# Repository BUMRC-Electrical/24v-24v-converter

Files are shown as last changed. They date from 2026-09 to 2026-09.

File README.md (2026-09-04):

<!-- kicad_template/README.md -->

<div align="center">
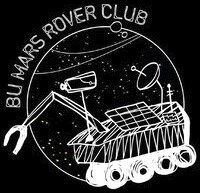
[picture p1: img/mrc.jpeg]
    
</div>

## 24V-24V 35 Amp Converter

This repository contains all documentation and files for the custom 24V Converter.

## File Structure

- ```/kicad/``` contains all of the KiCad 10.0 project files
- ```/datasheets/``` contains all of the .pdf files for the important components
- ```/calculations/``` contains significant calculations that led to a component choice or value choice
- ```/cad/``` currently contains no files
- ```24V_BOM.xlsx``` contains all components, quantities, and links to purchase

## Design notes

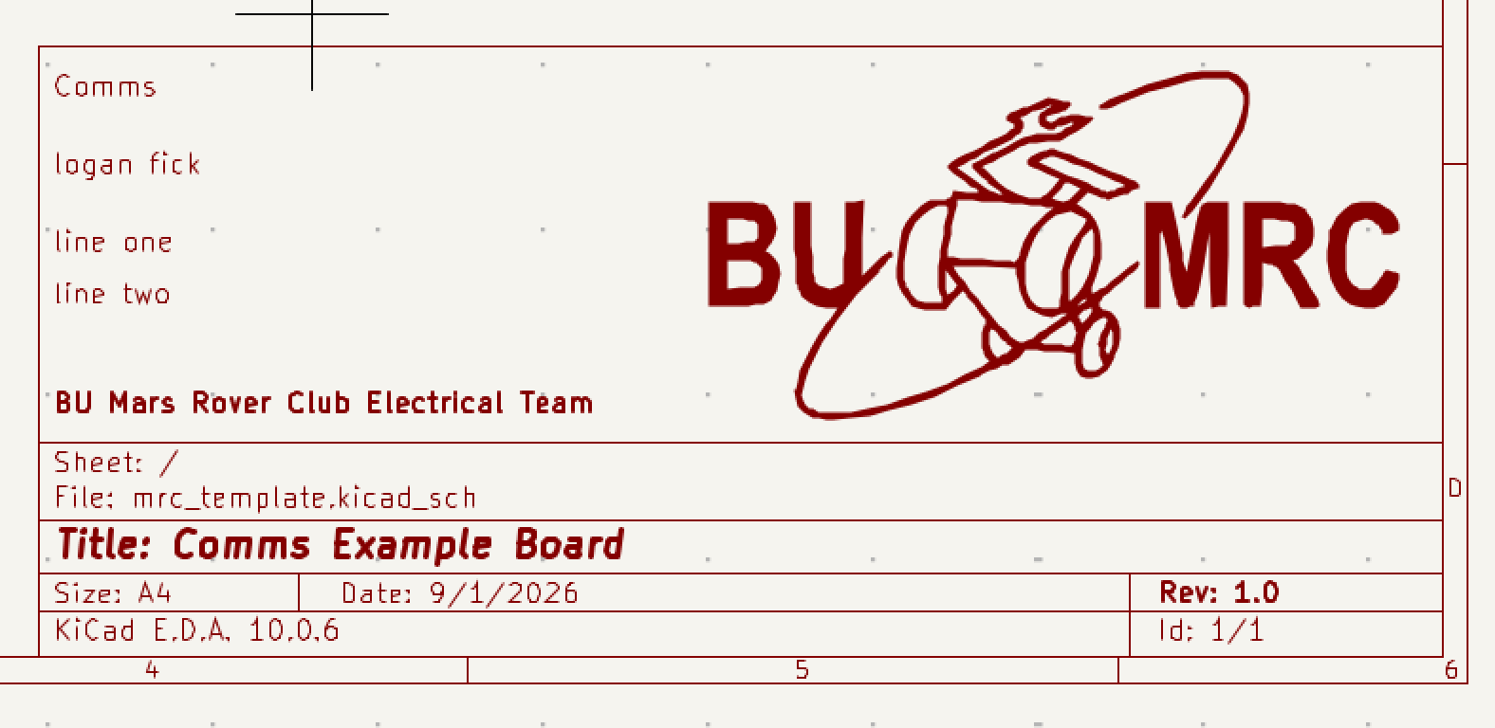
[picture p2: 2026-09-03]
img/fields.png

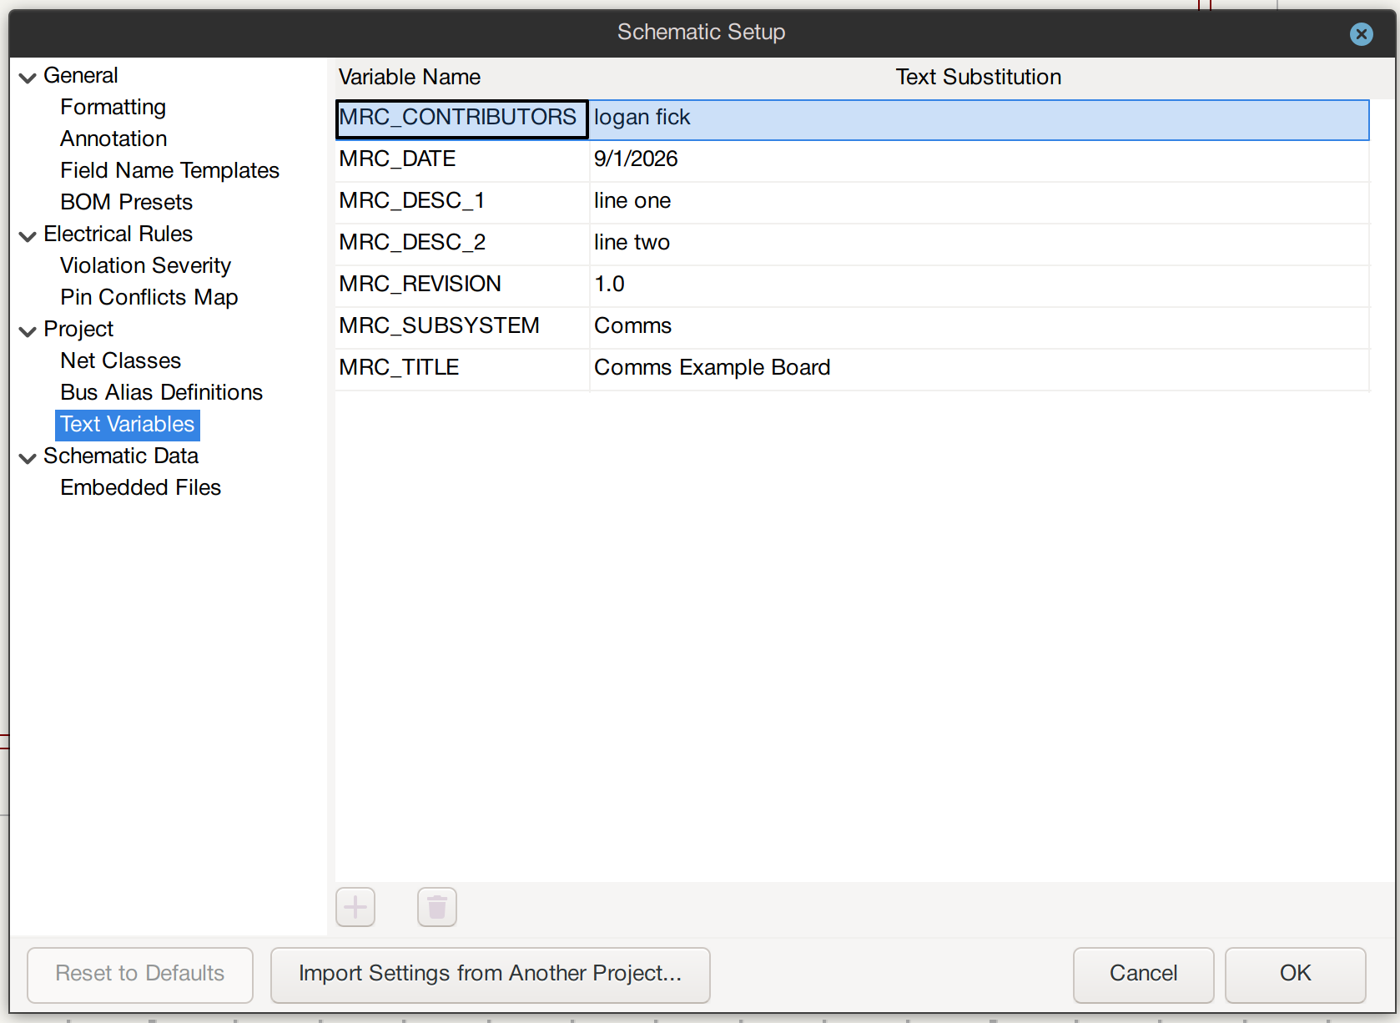
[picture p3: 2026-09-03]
img/text_variables.png

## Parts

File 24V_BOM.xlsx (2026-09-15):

Part | Part Number | Quantity | Footprint (mm²) | Description | Link | Replacement
Rvisns | CRCW04022K00FKED | 1 | 3 | Resistance: 2 kΩ Tolerance: 1.0% Power: 63 mW | https://www.digikey.com/en/products/detail/vishay-dale/CRCW04022K00FKED/1178039 | https://www.digikey.com/en/products/detail/stackpole-electronics-inc/RNCF0603TKY2K00/4928382
M1 & M2 | CSD18540Q5B | 4 | 56 | VdsMax: 60 V IdsMax: 200 Amps | https://www.mouser.com/en/ProductDetail/Texas-Instruments/CSD18540Q5B?qs=NRIcxvoDUteMaKTIEMaARQ%3D%3D
Cboot1/Cboot2 | 06033C104KAT2A | 2 | 4.68 | Cap: 100 nF Total Derated Cap: 100 nF VDC: 25 V ESR: 50 mΩ Package: 0603 | https://www.digikey.com/en/products/detail/kyocera-avx/KGM15BR71E104KT/1116240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
Rf | RC0603FR-0710RL | 1 | 4.68 | Resistance: 10 Ω Tolerance: 1.0% Power: 100 mW | https://www.digikey.com/en/products/detail/yageo/RC0603FR-0710RL/726879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 | https://www.digikey.com/en/products/detail/stackpole-electronics-inc/RNCF0805TKY10K0/2269701
Rcomp | CRCW04022K10FKED | 1 | 3 | Resistance: 2.1 kΩ Tolerance: 1.0% Power: 63 mW | https://www.digikey.com/en/products/detail/vishay-dale/CRCW04022K10FKED/1178041 | https://www.digikey.com/en/products/detail/koa-speer-electronics-inc/RK73H2ATTD1002F/10234111
Rpg | RC0603FR-0710KL | 1 | 4.68 | Resistance: 10 kΩ Tolerance: 1.0% Power: 100 mW | https://www.digikey.com/en/products/detail/yageo/RC0603FR-0710KL/726880
C32, C33 | MSASH21GSB7153MTNA01 | 2 | 6.75 | Cap: 15 nF Total Derated Cap: 30 nF VDC: 100 V ESR: 1.25 Ω Package: 0805 | https://www.digikey.com/en/products/detail/kyocera-avx/08051C163JAT2A/1601344
C34 | GRM2195C1H152JA01D | 1 | 6.75 | Cap: 1.5 nF Total Derated Cap: 1.5 nF VDC: 50 V ESR: 0 Ω Package: 0805 | https://www.digikey.com/en/products/detail/murata-electronics/GRM2195C1H152JA01D/2545206
Dboot1 & Df | CUSTOM | 2 | NA | Type: ? VRRM: 36 V Io: 200 mA | https://www.digikey.com/en/products/detail/onsemi/BAS16HT1G/918301
Rsense | FCSL64R002GER | 1 | 43.16 | Resistance: 2 mΩ Tolerance: 2.0% Power: 2 W | https://www.digikey.com/en/products/detail/ohmite/FCSL64R002GER/1853755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
Dboot2 | CDBK0540-HF | 1 | 11.7 | Type: Schottky VRRM: 40 V Io: 500 mA | https://www.digikey.com/en/products/detail/mcc-micro-commercial-components/MBR0540-TP/717252
U1 | LM5176PWPR | 1 | 98.28 |  | https://www.digikey.com/en/products/detail/texas-instruments/LM5176PWPR/8105935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
C1-C7 | 50SVPF10M | 7 | 73.96 | Cap: 10 µF Total Derated Cap: 70 µF VDC: 50 V ESR: 40 mΩ Package: 6.3x6 | https://www.digikey.com/en/products/detail/panasonic-industry/50SVPF10M/4209237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 | https://www.digikey.com/en/products/detail/panasonic-industry/50SVPK10M/7564810
Cvcc | EMK107B7105KA-T | 1 | 4.68 | Cap: 1 µF Total Derated Cap: 1 µF VDC: 16 V ESR: 1 mΩ Package: 0603 | https://www.digikey.com/en/products/detail/taiyo-yuden/EMK107B7105KA-T/930593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
L1 | CUSTOM | 1 | NA | L: 1.25 µH DCR: 3.43 mΩ IDC: 56.94 A Data Sheet Recomends: 12.7µH and 16.5 A | https://www.digikey.com/en/products/detail/bourns-inc/SRP1770TA-100M/5429634
Ccs | 06035A470JAT2A | 1 | 4.68 | Cap: 47 pF Total Derated Cap: 47 pF VDC: 50 V ESR: 174 mΩ Package: 0603 | https://www.digikey.com/en/products/detail/kyocera-avx/KGM15ACG1H470JT/563281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
C13-C18 | 50SVPF39M | 6 | 106.09 | Cap: 39 µF Total Derated Cap: 230 µF VDC: 50 V ESR: 25 mΩ Package: 8x11.9 | https://www.digikey.com/en/products/detail/panasonic-industry/50SVPF39M/4204925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
M4 | IAUCN04S7L019ATMA1 | 1 | 31.92 | VdsMax: 40 V IdsMax: 144 Amps | https://www.digikey.com/en/products/detail/infineon-technologies/IAUCN04S7L019ATMA1/22157614
M3 | IAUCN04S7L028ATMA1 | 2 | 31.92 | VdsMax: 40 V IdsMax: 200 Amps | https://www.digikey.com/en/products/detail/infineon-technologies/IAUCN04S7L028ATMA1/22157720
Cf | CGA3E2X7R1H104K080AA | 1 | 4.68 | Cap: 100 nF Total Derated Cap: 100 nF VDC: 50 V ESR: 29.6 mΩ Package: 0603 | https://www.digikey.com/en/products/detail/tdk/CGA3E3X8R1H104K080AB/3954272
Cslope | CL10C221JB8NNNC | 1 | 4.68 | Cap: 220 pF Total Derated Cap: 220 pF VDC: 50 V ESR: 0 Ω Package: 0603 | https://www.digikey.com/en/products/detail/samsung-electro-mechanics/CL10C221JB8NNNC/3886706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
C8-12 C19-C23 C24-C28 | 35SVPF82M | 3 | 106.09 | Cap: 82 µF Total Derated Cap: 250 µF VDC: 35 V ESR: 20 mΩ Package: 8x11.9 | https://www.digikey.com/en/products/detail/panasonic-industry/35SVPF82M/4204894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
Css | C2012C0G1H223K125AA | 1 | 6.75 | Cap: 22 nF Total Derated Cap: 22 nF VDC: 50 V ESR: 0 Ω Package: 0805 | https://www.digikey.com/en/products/detail/tdk/C2012C0G1H223K125AA/3951553
Ruvb | CRCW040215K0FKED | 1 | 3 | Resistance: 15 kΩ Tolerance: 1.0% Power: 63 mW | https://www.digikey.com/en/products/detail/vishay-dale/CRCW040215K0FKED/1178139 | https://www.digikey.com/en/products/detail/ohmite/APC0603T15K0Z/16369600
Cbias | C0805C104M5RACTU | 1 | 6.75 | Cap: 100 nF Total Derated Cap: 100 nF VDC: 50 V ESR: 35.47 mΩ Package: 0805 | https://www.digikey.com/en/products/detail/kemet/C0805C104M5RACTU/411168
Rcsg | CRCW0603100RFKEA | 1 | 4.68 | Resistance: 100 Ω Tolerance: 1.0% Power: 100 mW | https://www.digikey.com/en/products/detail/vishay-dale/CRCW0603100RFKEA/1174554
Rfbb | RC0603FR-0720KL | 1 | 4.68 | Resistance: 20 kΩ Tolerance: 1.0% Power: 100 mW | https://www.digikey.com/en/products/detail/yageo/RC0603FR-0720KL/727040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
Rcsp | CRCW0603100RFKEA | 1 | 4.68 | Resistance: 100 Ω Tolerance: 1.0% Power: 100 mW | https://www.digikey.com/en/products/detail/vishay-dale/CRCW0603100RFKEA/1174554
Ruvt | CRCW0402249KFKED | 1 | 3 | Resistance: 249 kΩ Tolerance: 1.0% Power: 63 mW | https://www.digikey.com/en/products/detail/vishay-dale/CRCW0402249KFKED/1178278 | https://www.digikey.com/en/products/detail/panasonic-industry/ERA-3AEB2493V/2026962
C29-C31 | MSASU21GBB5475KTNA01 | 15 | 6.75 | Cap: 4.7 µF Total Derated Cap: 2.1 µF VDC: 50 V ESR: 10.31 mΩ Package: 0805 | https://www.digikey.com/en/products/detail/taiyo-yuden/MSASU21GBB5475KTNA01/16666988
Rfbt | RC0603FR-07576KL | 1 | 4.68 | Resistance: 576 kΩ Tolerance: 1.0% Power: 100 mW | https://www.digikey.com/en/products/detail/yageo/RC0603FR-07576KL/727311
Rt | CRCW040264K9FKED | 1 | 3 | Resistance: 64.9 kΩ Tolerance: 1.0% Power: 63 mW | https://www.digikey.com/en/products/detail/vishay-dale/CRCW040264K9FKED/1178214 | https://www.digikey.com/en/products/detail/stackpole-electronics-inc/RMCF0603FT64K9/1760863
Rmode | RC0603FR-0793K1L | 1 | 4.68 | Resistance: 93.1 kΩ Tolerance: 1.0% Power: 100 mW | https://www.digikey.com/en/products/detail/yageo/RC0603FR-0793K1L/727432
LED | 5962-XL-3216UGCTR-ND | 3 |  | Color: Green VF: 3.1V | https://www.digikey.com/en/products/detail/xinglight/XL-3216UGC/25673130
R Series | 118-CR1206-JW-752ELFTR-ND | 2 |  | R: 7.5 kOhms | https://www.digikey.com/en/products/detail/bourns-inc/CR1206-JW-752ELF/3785665

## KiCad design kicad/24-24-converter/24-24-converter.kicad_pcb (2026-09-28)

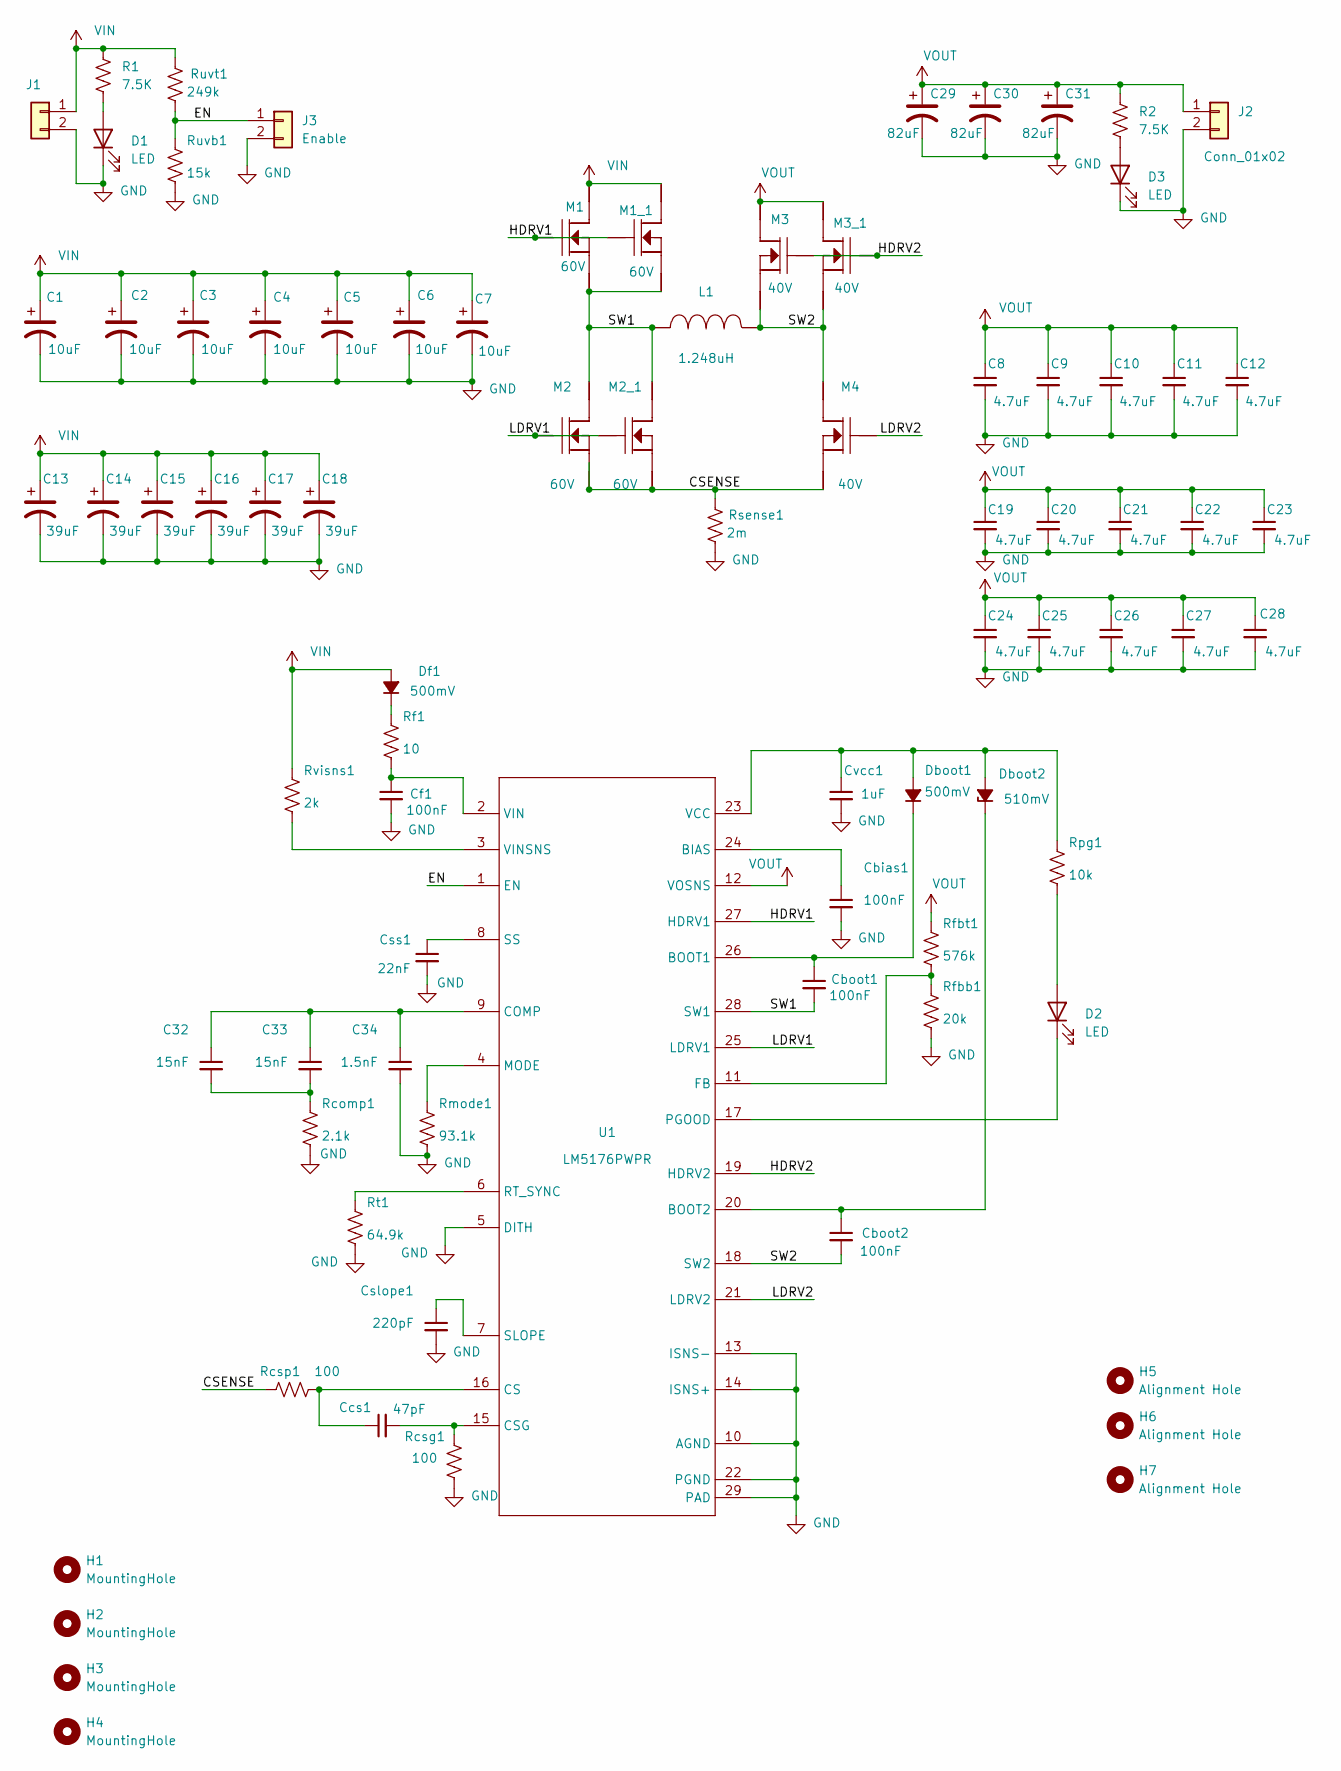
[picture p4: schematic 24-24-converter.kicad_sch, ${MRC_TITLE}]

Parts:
C1, C2, C3, C4, C5, C6, C7: 50SVPF10M; Cbulk_CAP_B6-SVPK_PAN; MANUFACTURER PART NUMBER 50SVPF10M
C8, C9, C10, C11, C12, C19, C20, C21, C22, C23, C24, C25, C26, C27, C28: MSASU21GBB5475KTNA01; C_0805_2012Metric_Pad1.18x1.45mm_HandSolder; MANUFACTURER PART NUMBER MSASU21GBB5475KTNA01
C13, C14, C15, C16, C17, C18: 50SVPF39M; Cin_50SVPF39M; MANUFACTURER PART NUMBER 50SVPF39M
C29, C30, C31: 35SVPF82M; PCAP_SVP_E12_PAN; MANUFACTURER PART NUMBER 35SVPF82M
C32, C33: MSASH21GSB7153MTNA01; C_0805_2012Metric_Pad1.18x1.45mm_HandSolder; MANUFACTURER PART NUMBER MSASH21GSB7153MTNA01
C34: GRM2195C1H152JA01D; C_0805_2012Metric_Pad1.18x1.45mm_HandSolder; MANUFACTURER PART NUMBER GRM2195C1H152JA01D
Cbias1: C0805C104M5RACTU; C_0805_2012Metric_Pad1.18x1.45mm_HandSolder; MANUFACTURER PART NUMBER C0805C104M5RACTU
Cboot1, Cboot2: 06033C104KAT2A; C_0805_2012Metric_Pad1.18x1.45mm_HandSolder; MANUFACTURER PART NUMBER 06033C104KAT2A
Ccs1: 06035A470JAT2A; C_0805_2012Metric_Pad1.18x1.45mm_HandSolder; MANUFACTURER PART NUMBER 06035A470JAT2A
Cf1: CGA3E2X7R1H104K080AA; C_0805_2012Metric_Pad1.18x1.45mm_HandSolder; MANUFACTURER PART NUMBER CGA3E2X7R1H104K080AA
Cslope1: CL10C221JB8NNNC; C_0603_1608Metric_Pad1.08x0.95mm_HandSolder; MANUFACTURER PART NUMBER CL10C221JB8NNNC
Css1: C2012C0G1H223K125AA; C_0603_1608Metric_Pad1.08x0.95mm_HandSolder; MANUFACTURER PART NUMBER C2012C0G1H223K125AA
Cvcc1: EMK107B7105KA-T; C_0603_1608Metric_Pad1.08x0.95mm_HandSolder; MANUFACTURER PART NUMBER EMK107B7105KA-T
D1, D2, D3: LED; LED_1206_3216Metric_Pad1.42x1.75mm_HandSolder
Dboot1: GENERIC_DIODE; Diode_BAS16HT1G; MANUFACTURER PART NUMBER GENERIC_DIODE
Dboot2: CDBK0540-HF; Shottkey_MBR0540-TP; MANUFACTURER PART NUMBER CDBK0540-HF
Df1: GENERIC_DIODE; Diode_BAS16HT1G; MANUFACTURER PART NUMBER GENERIC_DIODE
H1, H2, H3, H4: MountingHole; MountingHole_2.5mm
H5, H6, H7: Alignment Hole
J1, J2: Conn_01x02; AMASS_XT60-F_1x02_P7.20mm_Vertical
J3: Enable; PinHeader_1x02_P1.00mm_Vertical
L1: GENERIC_INDUCTOR; L-SRP1770TA-100M_1; MANUFACTURER PART NUMBER GENERIC_INDUCTOR
M1, M1_1, M2, M2_1: CSD18540Q5B; MOSFET_CSD18540Q5B; MANUFACTURER PART NUMBER CSD18540Q5B
M3, M3_1, M4: GENERIC_MOSFET_N; MOSFET_CSD18540Q5B; MANUFACTURER PART NUMBER GENERIC_MOSFET_N
R1, R2: 7.5K; R_1206_3216Metric_Pad1.30x1.75mm_HandSolder
Rcomp1: CRCW04022K10FKED; R_0805_2012Metric_Pad1.20x1.40mm_HandSolder; MANUFACTURER PART NUMBER CRCW04022K10FKED
Rcsg1: CRCW0603100RFKEA; R_0603_1608Metric_Pad0.98x0.95mm_HandSolder; MANUFACTURER PART NUMBER CRCW0603100RFKEA
Rcsp1: CRCW0603100RFKEA; R_0603_1608Metric_Pad0.98x0.95mm_HandSolder; MANUFACTURER PART NUMBER CRCW0603100RFKEA
Rf1: RC0603FR-0710RL; R_0805_2012Metric_Pad1.20x1.40mm_HandSolder; MANUFACTURER PART NUMBER RC0603FR-0710RL
Rfbb1: RC0603FR-0720KL; R_0603_1608Metric_Pad0.98x0.95mm_HandSolder; MANUFACTURER PART NUMBER RC0603FR-0720KL
Rfbt1: RC0603FR-07576KL; R_0603_1608Metric_Pad0.98x0.95mm_HandSolder; MANUFACTURER PART NUMBER RC0603FR-07576KL
Rmode1: RC0603FR-0793K1L; R_0603_1608Metric_Pad0.98x0.95mm_HandSolder; MANUFACTURER PART NUMBER RC0603FR-0793K1L
Rpg1: RC0603FR-0710KL; R_0603_1608Metric_Pad0.98x0.95mm_HandSolder; MANUFACTURER PART NUMBER RC0603FR-0710KL
Rsense1: FCSL64R002GER; RSense_FCSL64R002GER; MANUFACTURER PART NUMBER FCSL64R002GER
Rt1: CRCW040264K9FKED; R_0603_1608Metric_Pad0.98x0.95mm_HandSolder; MANUFACTURER PART NUMBER CRCW040264K9FKED
Ruvb1: CRCW040215K0FKED; R_0603_1608Metric_Pad0.98x0.95mm_HandSolder; MANUFACTURER PART NUMBER CRCW040215K0FKED
Ruvt1: CRCW0402249KFKED; R_0603_1608Metric_Pad0.98x0.95mm_HandSolder; MANUFACTURER PART NUMBER CRCW0402249KFKED
Rvisns1: CRCW04022K00FKED; R_0603_1608Metric_Pad0.98x0.95mm_HandSolder; MANUFACTURER PART NUMBER CRCW04022K00FKED
U1: LM5176PWPR; MANUFACTURER PART NUMBER LM5176PWPR

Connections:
/CSENSE: M2.1 (Source), M2.2 (Source), M2.3 (Source), M2_1.1 (Source), M2_1.2 (Source), M2_1.3 (Source), M4.1 (Source), M4.2 (Source), M4.3 (Source), Rcsp1.1, Rsense1.1
/EN: J3.1, Ruvb1.1, Ruvt1.2, U1.1 (EN)
/HDRV1: M1.4 (Gate), M1_1.4 (Gate), U1.27 (HDRV1)
/HDRV2: M3.4 (Gate), M3_1.4 (Gate), U1.19 (HDRV2)
/LDRV1: M2.4 (Gate), M2_1.4 (Gate), U1.25 (LDRV1)
/LDRV2: M4.4 (Gate), U1.21 (LDRV2)
/SW1: Cboot1.2, L1.1, M1.1 (Source), M1.2 (Source), M1.3 (Source), M1_1.1 (Source), M1_1.2 (Source), M1_1.3 (Source), M2.5 (Drain), M2.6 (Drain), M2.7 (Drain), M2.8 (Drain), M2.9 (Drain), M2_1.5 (Drain), M2_1.6 (Drain), M2_1.7 (Drain), M2_1.8 (Drain), M2_1.9 (Drain), U1.28 (SW1)
/SW2: Cboot2.2, L1.2, M3.1 (Source), M3.2 (Source), M3.3 (Source), M3_1.1 (Source), M3_1.2 (Source), M3_1.3 (Source), M4.5 (Drain), M4.6 (Drain), M4.7 (Drain), M4.8 (Drain), M4.9 (Drain), U1.18 (SW2)
GND: C1.2, C2.2, C3.2, C4.2, C5.2, C6.2, C7.2, C8.2, C9.2, C10.2, C11.2, C12.2, C13.2, C14.2, C15.2, C16.2, C17.2, C18.2, C19.2, C20.2, C21.2, C22.2, C23.2, C24.2, C25.2, C26.2, C27.2, C28.2, C29.2, C30.2, C31.2, C34.2, Cbias1.2, Cf1.2, Cslope1.2, Css1.2, Cvcc1.2, D1.1 (K), D3.1 (K), J1.2, J2.2, J3.2, Rcomp1.2, Rcsg1.2, Rfbb1.2, Rmode1.2, Rsense1.2, Rt1.2, Ruvb1.2, U1.5 (DITH), U1.10 (AGND), U1.13 (ISNS-), U1.14 (ISNS+), U1.22 (PGND), U1.29 (PAD)
unnamed: C32.2, C33.2, Rcomp1.1
unnamed: D1.2 (A), R1.2
unnamed: D2.2 (A), Rpg1.2
unnamed: D2.1 (K), U1.17 (PGOOD)
unnamed: D3.2 (A), R2.2
unnamed: Cvcc1.1, Dboot1.2 (A), Dboot2.2 (A), Rpg1.1, U1.23 (VCC)
unnamed: Cboot1.1, Dboot1.1 (K), U1.26 (BOOT1)
unnamed: Cboot2.1, Dboot2.1 (K), U1.20 (BOOT2)
unnamed: Df1.1 (K), Rf1.1
unnamed: Cbias1.1, U1.24 (BIAS)
unnamed: C32.1, C33.1, C34.1, U1.9 (COMP)
unnamed: Ccs1.1, Rcsp1.2, U1.16 (CS)
unnamed: Ccs1.2, Rcsg1.1, U1.15 (CSG)
unnamed: Rfbb1.1, Rfbt1.2, U1.11 (FB)
unnamed: Rmode1.1, U1.4 (MODE)
unnamed: Rt1.1, U1.6 (RT_SYNC)
unnamed: Cslope1.1, U1.7 (SLOPE)
unnamed: Css1.1, U1.8 (SS)
unnamed: Cf1.1, Rf1.2, U1.2 (VIN)
unnamed: Rvisns1.2, U1.3 (VINSNS)
VIN: C1.1, C2.1, C3.1, C4.1, C5.1, C6.1, C7.1, C13.1, C14.1, C15.1, C16.1, C17.1, C18.1, Df1.2 (A), J1.1, M1.5 (Drain), M1.6 (Drain), M1.7 (Drain), M1.8 (Drain), M1.9 (Drain), M1_1.5 (Drain), M1_1.6 (Drain), M1_1.7 (Drain), M1_1.8 (Drain), M1_1.9 (Drain), R1.1, Ruvt1.1, Rvisns1.1
VOUT: C8.1, C9.1, C10.1, C11.1, C12.1, C19.1, C20.1, C21.1, C22.1, C23.1, C24.1, C25.1, C26.1, C27.1, C28.1, C29.1, C30.1, C31.1, J2.1, M3.5 (Drain), M3.6 (Drain), M3.7 (Drain), M3.8 (Drain), M3.9 (Drain), M3_1.5 (Drain), M3_1.6 (Drain), M3_1.7 (Drain), M3_1.8 (Drain), M3_1.9 (Drain), R2.1, Rfbt1.1, U1.12 (VOSNS)

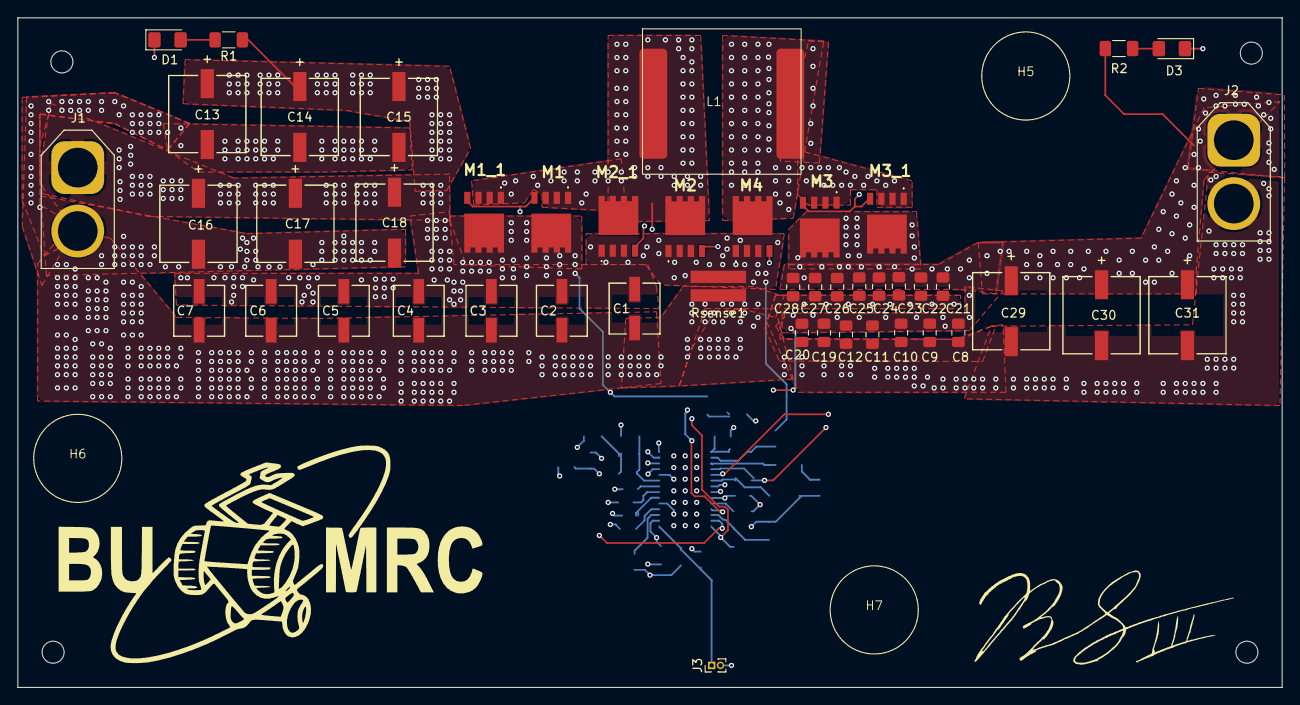
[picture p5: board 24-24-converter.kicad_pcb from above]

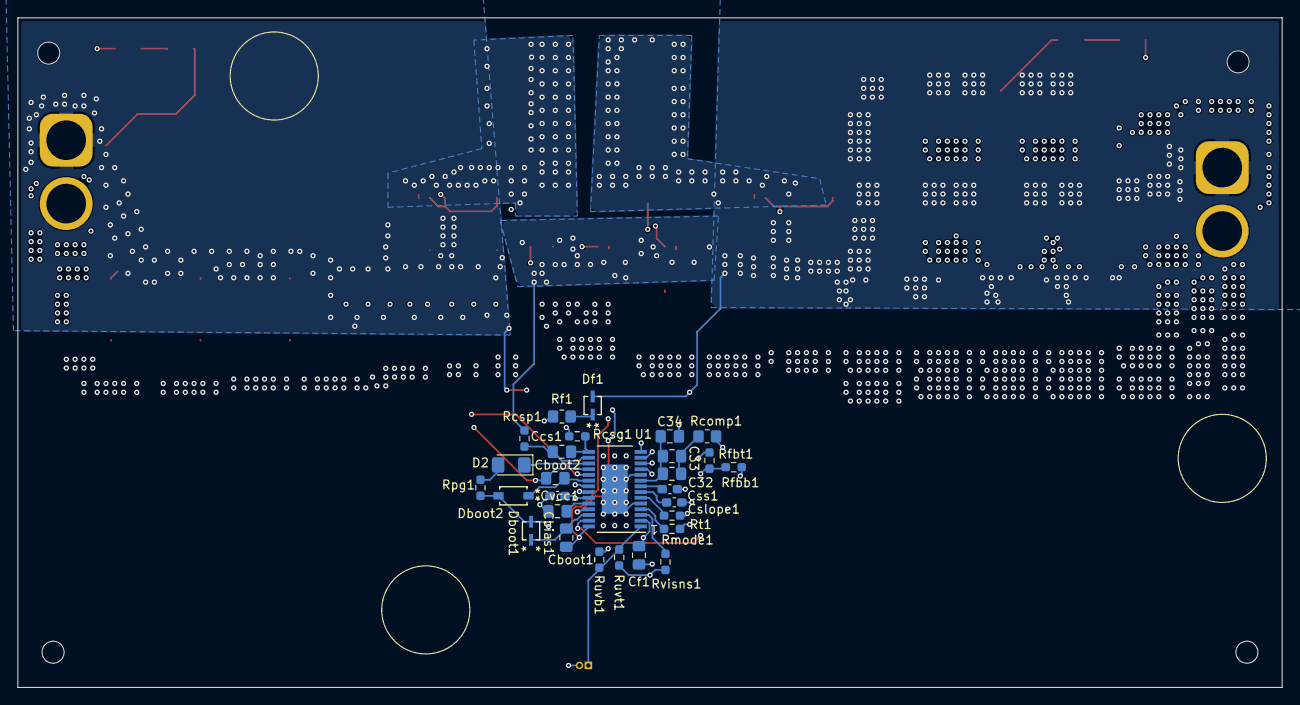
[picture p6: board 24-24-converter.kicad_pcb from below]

Board: 4 copper layers, 143.5 x 76.0 mm, 82 parts (28 on the bottom side), 31 nets.

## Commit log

2026-09-04 cloning files
    [.kicad_sch, 24V-Converter.kicad_sch, 24V_Converter.kicad_pcb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]
2026-09-04 import project files, remove template project
    [.kicad_sch, 24-24-converter.kicad_pcb, 24-24-converter.kicad_sch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]
2026-09-04 added logo to pcb
    [24-24-converter.kicad_pcb]
2026-09-04 Revert "added logo to pcb"
    This reverts commit 681fcdcd3ab6006da68f53ce5ce7633c7e1cffa3.
    [24-24-converter.kicad_pcb]
2026-09-04 revert crashing pcb file
2026-09-04 added documents
    [24-24-converter.kicad_pcb, 24V_BOM.xlsx, System_Calculations.xlsx]
2026-09-04 added filled zones
    [24-24-converter.kicad_pcb, 24-24-converter.kicad_sch]
2026-09-06 moved via's
    [24-24-converter.kicad_pcb]
2026-09-06 added high current paths to Coutx
    [24-24-converter.kicad_pcb]
2026-09-06 added old design for reference
    [24-24-converter.kicad_pcb, Charlie_Converter.kicad_pcb, Charlie_Converter.kicad_sch]
2026-09-07 Routing Attempt #2
    [24-24-converter.kicad_pcb]
2026-09-07 All new routing around U1
    [24-24-converter.kicad_pcb]
2026-09-07 Added Watermark
    [24-24-converter.kicad_pcb]
2026-09-08 Routing Attempt #3
    [24-24-converter.kicad_pcb, 24-24-converter.kicad_sch]
2026-09-09 Routing Attempt #4
    [24-24-converter.kicad_pcb, 24-24-converter.kicad_sch]
2026-09-11 Resolved DRC Flags
    [24-24-converter.kicad_pcb]
2026-09-14 Updated Systems Calculations
    [System_Calculations.xlsx]
2026-09-15 Routing Attempt #5
    [24-24-converter.kicad_pcb, 24-24-converter.kicad_sch, 24V_BOM.xlsx]
2026-09-15 Fixed Capacitor
    [24-24-converter.kicad_pcb, 24V_BOM.xlsx]
2026-09-15 fixedenable connector issue
    [24-24-converter.kicad_pcb, 24-24-converter.kicad_sch]
2026-09-15 fixed enable issue
    [24-24-converter.kicad_pcb]
2026-09-21 Fixed chip footprint
    [24-24-converter.kicad_pcb, System_Calculations.xlsx]
2026-09-21 Thermal Relief on Connectors
    [24-24-converter.kicad_pcb]
2026-09-28 Added Alignment Holes and created Gerbers
    [24-24-converter-B_Cu.gbr, 24-24-converter-B_Mask.gbr, 24-24-converter-B_Paste.gbr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]

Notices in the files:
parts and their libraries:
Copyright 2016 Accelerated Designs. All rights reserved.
